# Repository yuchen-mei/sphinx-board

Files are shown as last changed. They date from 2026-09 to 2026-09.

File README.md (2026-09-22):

# Sphinx ASIC Test Board

Sphinx is a test board for voltage, frequency, power, and energy-efficiency characterization of a TSMC N7 ASIC. The nominal operating point is 0.75 V core supply, approximately 5 W during kernel execution, and a target clock frequency of 1 GHz. A local programmable regulator, distributed decoupling, and differential feedback at the socket provide the board-level power delivery path.

Hardware: **V2**. This package contains the current schematic project, local KiCad libraries, BOM, schematic exports, and design documentation. The [Pico controller source](../controller/README.md) is maintained alongside this package. There is no V2 PCB, completed host test application, or board measurement evidence in the current repository.

## Design files

Open [schematic/sphinx_power_v2.kicad_pro](schematic/sphinx_power_v2.kicad_pro) in KiCad 10.

| File | Contents |
|---|---|
| [Schematic PDF](schematic/exports/sphinx_power_v2.pdf) | Eleven schematic sheets |
| [XML netlist](schematic/exports/sphinx_power_v2.net.xml) | Component connections |
| [Parts catalog](schematic/bom/parts_catalog.json) | Exact parts, assembly options, and application notes |
| [Purchase list](schematic/bom/BUY_LIST.csv) | Quantities for five boards and spares |
| [Component list](schematic/bom/component_list.csv) | Schematic components and fields |
| [Documentation](docs/README.md) | Requirements, interfaces, layout constraints, and verification |
| [Maintenance](CONTRIBUTING.md) | Editing and validation procedure |

## Operating scope

The core regulator covers 0.30–1.20 V. The lower end supports low-voltage energy-efficiency measurements. The conservative continuous-current design target is 10 A. I/O operates at a fixed 1.8 V. The supported operating region is determined experimentally for each device and workload; the regulator range does not define an ASIC voltage rating.

The board uses explicit `SET` / `ON` commands to program and enable the supplies. Once a command completes, the regulator and board-powered GPIO expander retain the voltage, enable and explicit reset state while 12 V remains valid. Pico restart, USB disconnect, firmware stop or Pico removal does not change that state. The [autonomous power contract](docs/AUTONOMOUS_POWER.md) defines the hardware, recovery rules and acceptance tests. Independent protection and the STOP button remain active without Pico. DUT reset is a separate, active-high control: the local button, remote optocoupler, or an explicit Pico command asserts it. With valid VIO and no request, reset is released without depending on the Pico, power-good signals, or run-latch state.

Functionality testing runs one kernel and checks its output. Power testing runs a large back-to-back kernel loop and reads averaged voltage, current, and power after operation settles. Ordinary PG/undervoltage observations, PMBus warnings, and USB inactivity are reported without resetting or shutting down the DUT. Independent board core/I/O overvoltage and local temperature protection clear the hardware run latch. The core regulator and input eFuse also retain their own protection; a regulator-only fault can stop Core without clearing I/O. STOP and latched protective trips require a new explicit `ON`; internally latched eFuse faults can require cycling the 12 V input. Full board-power loss returns to OFF. Partial input brownouts are outside the state-retention guarantee and must be characterized; regulator and control-domain resets need not occur together.

The 10 A target still requires PCB resistance, loop stability, transient, socket/package, and sustained thermal qualification. Controller commissioning and calibration are required before unrestricted operation; a passing source-level check does not establish board readiness.

The controller follows the [startup interface](docs/RESET_AND_CONTROL.md). File checksums and verification scope are recorded in [PROVENANCE.json](PROVENANCE.json).

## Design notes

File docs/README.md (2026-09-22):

# Design Documentation

These documents describe the V2 schematic design and its required behavior. Start with the circuit description and operating procedure if you know the ASIC but are new to the board. Completed design checks and pending board measurements are distinguished in the verification document.

| Document | Scope |
|---|---|
| [Requirements](REQUIREMENTS.md) | Experiment, operating range, and design objectives |
| [Circuit description](DESIGN.md) | Power paths, protection, and telemetry |
| [Autonomous power](AUTONOMOUS_POWER.md) | Retained power/reset state, independent protection, command completion, and Pico-loss acceptance tests |
| [Power configuration](POWER_CONFIGURATION.md) | PMBus address, capacitor populations, and compensation settings |
| [Reset and control](RESET_AND_CONTROL.md) | Controller ON/OFF, fault latch, STOP, and local/remote reset |
| [I/O enable interface](IO_ENABLE.md) | Circuit connections and transient verification |
| [Layout requirements](LAYOUT_HANDOFF.md) | Power delivery, probing, signals, and mechanical integration |
| [Verification](VALIDATION.md) | Schematic evidence and board measurement plan |
| [Final source review](FINAL_REVIEW_2026-09-22.md) | Completed independent review, corrections, and remaining physical qualification |
| [References](REFERENCES.md) | Manufacturer documents and their applicability |

The [schematic](../schematic/exports/sphinx_power_v2.pdf), [netlist](../schematic/exports/sphinx_power_v2.net.xml), [parts catalog](../schematic/bom/parts_catalog.json), and [component list](../schematic/bom/component_list.csv) define component population and connections. Sheet 09 covers autonomous control and sheet 10 independent protection. Use [current generated evidence](VALIDATION.md) for design counts and check results; this documentation does not maintain duplicate fixed totals.

The normal workflow is one checked `ON`, an explicit reset with the external clock running, then either one kernel for functional correctness or a large back-to-back kernel loop followed by steady voltage/current/power measurements. Once a power command succeeds, continuously valid 12 V and healthy hardware retain operation through Pico inactivity, USB disconnection, reboot, or loss of Pico power. Complete board input loss defaults OFF when power returns. Measurements are requested when needed; they are not a power-sustain heartbeat.

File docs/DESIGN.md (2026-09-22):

# Circuit Description

## Power paths

The core path is J101/J102, F101, U101, U201/L201, R201, and the socket supply plane. U201 is a TPS546B24ARVFR synchronous buck regulator. L201 is 0.56 µH and the configured switching frequency is 650 kHz. Differential feedback returns from the socket-side net ties NT601 and NT602, after the 1 mΩ core current shunt R201.

At 10 A, R201 has a nominal 10 mV drop and dissipates 0.10 W. Feedback includes this shunt and the PCB path to the sense endpoint. It excludes socket and package impedance. The WSL shunts are two-terminal devices; route independent sense traces from their pads.

U301 is the fixed-output TPS62131RGTR, supplying 1.8 V through L301 and the 10 mΩ I/O shunt R301. TPS62133 is a different output-voltage variant and is not a substitute. The enable circuit is specified in [IO_ENABLE.md](IO_ENABLE.md).

U102 supplies AUX5V through the 73.2 kΩ / 10 kΩ feedback network. U901, TLV75533PDBVR, independently generates `3V3_CTRL` from AUX5V with its enable tied to AUX5V. D401 supplies Pico VSYS from AUX5V, but Pico pin 36 does not supply `3V3_CTRL`. Removing or rebooting the Pico therefore does not remove board control power. Follow the schematic power connections when combining USB and board input power.

Sheet 09 contains the autonomous control interface: U902 ISO1640BDR separates board-side I2C on side 1 from Pico-side I2C on side 2. Pico GP0/GP1 are its only GPIO connections, carrying SDA/SCL. Each bus side has its own supply and pullups. U903 TCA9535PWR retains output requests and reads digital status; U904 ADS1115IDGSR reads the NTC and its excitation supply. Sheet 10 contains independent temperature and I/O overvoltage protection. See [AUTONOMOUS_POWER.md](AUTONOMOUS_POWER.md) for the complete pin map and power-domain contract.

## Input protection and run latch

F101 is a 3.15 A backup fuse. U101 is a TPS259470L eFuse. Its 1.24 kΩ ILM resistor sets a nominal 2.69 A current limit. Input UVLO and OVLO are approximately 10.64 V and 14.4 V. These are nominal circuit thresholds; evaluate tolerances and fault transients during verification.

U509 senses VIN12 after the eFuse and reports `VIN12_VALID` to U903 P11, with R516 providing its 10 kΩ pull-up. This observation does not clear the run latch. U503 is the hardware fault latch: pin 5 is Q (`RUN_LATCH`), and its unused Q-bar output is left unconnected. STOP, an asserted eFuse fault output, control-supply brownout, independent Core/I/O overvoltage, and independent board overtemperature participate in the hardware clear path. U507 conditions the fault bus into `HW_CLEAR_N`, which asynchronously clears U503.

The controller commands U903 P03 to pulse `RUN_SET` through U507 during an explicit ON startup. R507 holds this input low before U903 is initialized. A hardware clear acts even if the Pico is absent or retained enable requests remain high; recovery alone cannot set the cleared latch again. `ON` verifies discharge and configuration, checks the fault bus, and generates one set pulse. A scale-changing SET while ON disables rail requests, checks discharge, and reconfigures while preserving the existing run latch; it restores requests only if that latch remains set and never generates another set pulse. Repeated ON at the matching established state checks it without cycling power. OFF pulses U903 P04 `CLEAR_REQUEST` high through Q901 to clear the latch, then returns P04 low. These actions preserve U903 P02's explicit DUT reset request.

The eFuse has its own operating and fault behavior. UVLO and OVLO inhibit its output without necessarily asserting its fault output. Recovery with the original operating point requires both retained control state and retained regulator configuration; a dip that resets PMBus settings while AUX/control power survives is a separate qualification case. USB does not sustain the independent control domain. Control brownout or an asserted eFuse fault clears the latch; a complete input loss and discharge defaults OFF on return. An internally latched eFuse fault can also require cycling 12 V. See [RESET_AND_CONTROL.md](RESET_AND_CONTROL.md).

U502 supervises `3V3_CTRL`. R1001 = 100 kΩ connects its CT pin to `3V3_CTRL`, selecting a nominal 300 ms startup holdoff, specified 180–420 ms. The TMP302 datasheet describes 35 ms as typical in §8.2.3 and states in §9 that U1001 becomes fully functional within 35 ms after its supply reaches 1.4 V. The 180 ms minimum holdoff provides startup margin for a normal monotonic supply ramp. Qualify the assembled clear path during hot startup and nonmonotonic supply ramps; see [AUTONOMOUS_POWER.md](AUTONOMOUS_POWER.md).

U504, a Diodes Incorporated 74LVC08AT14-13 in TSSOP-14, implements the two supply-enable AND functions:

```text
CORE_EN      = RUN_LATCH AND CORE_REQ
IO_EN_CTRL   = RUN_LATCH AND IO_REQ
```

The unused third and fourth gates have their inputs grounded and outputs unconnected. U506 and C507 are absent; no logic gate combines power-good or run-latch signals with DUT reset. U507 remains part of the power-latch circuit.

| Detector | Sense network | Nominal threshold | Function |
|---|---|---:|---|
| U501 | 1.24 kΩ / 20 kΩ | 1.319 V | Independent core overvoltage, clears run latch |
| U509 | 73.2 kΩ / 10 kΩ | 10.333 V | Post-eFuse input-voltage observation on `VIN12_VALID`; warning only |
| U508 | 6.19 kΩ / 20 kΩ | 1.626 V | I/O voltage observation on `IO_VALID`; warning only |
| U1001 | TMP302B straps: TRIPSET0 high, TRIPSET1 low, HYSTSET low | 75°C, nominal 5°C hysteresis | Independent local board-temperature protection; clears run latch |
| U1002 | R1002 = 12.6 kΩ / R1003 = 20 kΩ, both 0.1% | 2.02446 V | Independent socket-side I/O overvoltage; clears run latch |

The fixed Core OVP is a board fault threshold. The controller programs regulator overvoltage, overtemperature, and excessive-current protection once and verifies readback; protection then operates without Pico service. C1001/C1002 locally bypass U1001/U1002. TMP302B accuracy is ±2°C before placement error. The I/O comparator threshold has an approximate 1.943–2.106 V initial static screening range, not a guaranteed 2.025 V ceiling. Ordinary PG loss, undervoltage, voltage deviation, PMBus warnings, and communication loss are diagnostic observations; they do not request shutdown or reset. The 10 A continuous target and routine current budgets are qualification limits and warnings, not instantaneous current clamps. No protection threshold establishes an ASIC absolute-maximum rating.

Take the U501 sense connection independently from the socket core plane. A break in the narrow feedback branch must not also disconnect the OVP sense path. U508 directly measures I/O voltage; U301 PG alone does not establish that an operating I/O supply is present.

## Reset

R602 pulls J1.54 to I/O voltage through 10 kΩ. R603 biases Q601's base from VIO through 21.5 kΩ; R604 provides the 100 kΩ base pull-down. With valid VIO, Q601 normally conducts and pulls J1.54 low to release reset. SW601, optocoupler U601, and U903-controlled Q602 independently pull `RESET_BASE` low to turn Q601 off and assert active-high reset:

```text
RESET_ASSERTED = LOCAL_RESET OR REMOTE_RESET OR RETAINED_RESET_ASSERT
```

This expression applies while VIO provides valid logic levels. U903 P02 is `RESET_ASSERT`: high requests reset, and low releases that request. R411 keeps the request inactive when U903 is in its cold-start input state. Once programmed, this request survives Pico loss or reboot. An explicit reset command leaves the power requests and latch unchanged; power commands and protective shutdown leave the retained reset request unchanged. Reset is not automatically driven by invalid power. Its high level is unavailable when VIO is absent. There is no pulse stretcher or clock synchronizer; the operator supplies an adequate explicit pulse with the external clock running.

TP7 measures the actual J1.54 reset node; TP607 supplies the adjacent probe ground. See [RESET_AND_CONTROL.md](RESET_AND_CONTROL.md).

## Decoupling and telemetry

The default core population is 12 × 330 µF polymer, 12 × 100 µF MLCC, 16 × 1 µF, and 16 × 100 nF. Total nominal capacitance is 5177.6 µF. The board reserves four additional polymer and four additional large-MLCC positions. Assembly options and controller settings are specified in [POWER_CONFIGURATION.md](POWER_CONFIGURATION.md).

R212 (47 Ω) and R304 (100 Ω) discharge Core and I/O. Confirm output voltage before a range change or hardware reconfiguration; disabling a regulator does not immediately discharge its output.

Two INA226 devices at 7-bit addresses 0x40 (Core) and 0x41 (I/O) measure rail voltage and current. With configuration `0x4297`, four averages of 332 µs bus and 332 µs shunt conversions give a nominal 2.656 ms update period. U201 PMBus is at 0x10, U903 at 0x20, and U904 at 0x48. U904 AIN0/AIN1 measure `BOARD_NTC`/`3V3_CTRL` for a calibrated ratiometric temperature reading. Reading telemetry is optional for power retention. Use an oscilloscope for kernel transients and reset pulses.

The core shunt measures regulator current before local decoupling. Capacitor-supplied load current is not measured directly at that shunt. During a sustained back-to-back kernel loop, average capacitor charging current approaches zero, so averaged shunt current is useful for steady rail-power measurement. INA226 VBUS is referenced to its local ground; it is not a die-side differential voltage measurement. The reported rail power includes downstream board loads and socket/package losses. R212 consumes about 12 mW at 0.75 V and R304 consumes 32.4 mW at 1.8 V; account for these loads when estimating DUT supply power. Input current requires an external instrument.

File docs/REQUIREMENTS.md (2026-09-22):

# Design Requirements

## Experiment

The board supports characterization of a TSMC N7 ASIC across core voltage, clock frequency, and workload. Functionality testing runs a kernel once and compares its output with the expected result. Power testing runs the kernel in a large back-to-back loop, waits for steady operation, and reads averaged voltage, current, and power. Power delivery must accommodate both the sustained load and the transitions at kernel start and completion.

| Parameter | Requirement or experiment input |
|---|---|
| Nominal core voltage | 0.75 V |
| Active core power | Approximately 5 W at the nominal operating point, supplied as an experiment input |
| Nominal active current | Approximately 6.67 A, calculated as 5 W / 0.75 V |
| Clock frequency | 1 GHz target; higher frequencies are characterization points |
| Core adjustment range | 0.30–1.20 V; default sweep increment 50 mV |
| Continuous core current | 10 A conservative board design target |
| I/O supply | Fixed 1.8 V; 1 A provisioned load budget |
| Input supply | 12 V nominal; 11.5–13 V operating target at the input terminals |
| Control | Pico USB commands through isolated I2C, retained board-side requests, hardware fault latch and STOP, local and remote DUT reset |
| Telemetry | Core and I/O voltage/current, plus board temperature |
| Initial build | Five boards plus component spares |

The adjustment range is a superset of the intended experimental operating points. The 0.30 V lower limit supports low-voltage energy-efficiency measurements. Approximately 1.0 V is an empirically supported boost point for the available devices. No device absolute-maximum voltage is specified. Select boost voltage, frequency, and workload per device and record the measured operating conditions.

I/O voltage is fixed because the experiment does not require an I/O voltage sweep and the I/O load is small. The 1 A budget is provisioning, not a measured I/O consumption value.

Minimize routine experiment steps: one `ON` command performs configuration checks and starts the supplies. After successful completion, with continuously valid 12 V and no hardware fault or STOP, the established supply configuration and explicit reset request must survive Pico inactivity, USB disconnection, firmware restart, and complete loss of Pico power. The board must not require periodic Pico execution or bus traffic. Reset is a separate explicit user or experiment-script action. Ordinary power-good loss, undervoltage, voltage deviation, PMBus warnings, and communication loss are diagnostic; observations collected on demand must not reset the DUT or stop the experiment.

Retain independent hardware protection against damaging overvoltage, overtemperature, and excessive current, together with explicit `OFF` and hardware STOP. Board temperature and I/O overvoltage protection must not depend on software samples. A cleared run latch must not restart automatically when its cause clears; a new explicit `ON` requests recovery. Regulator/eFuse intrinsic lockout and loss of control power remain physical operating constraints. An intrinsic input interruption can recover transparently only if the control state and regulator configuration both survive; partial brownouts require qualification. After complete 12 V loss and board discharge, restored power must default OFF and require fresh configuration and explicit `ON`.

The [autonomous power contract](AUTONOMOUS_POWER.md) defines the retained interface and acceptance tests. A command interrupted before verified completion has an unknown outcome and must not be automatically replayed. Reconnecting the Pico first reads the existing board state; it must not initialize active outputs to defaults.

## Power delivery

Minimize board resistance and transient voltage excursions through local regulation, short current paths, distributed capacitance, and socket-side differential feedback. Evaluate voltage at multiple socket power/ground groups under static and pulsed loads. Record droop, overshoot, recovery time, and reset activity. Numerical droop acceptance limits are not specified.

The feedback endpoint is on the PCB. Socket contacts, bond wires, and the on-chip power grid lie beyond that endpoint. Package and socket replacement are design options. The package concerns are bond-wire geometry and encapsulant thermal conductivity; no numerical parasitic or thermal model is assigned without corresponding data.

## Reset and sequencing

DUT reset is active high at 1.8 V. The clock must run during reset. Reset release is asynchronous; no clock-synchronized release is required by the experiment. Manual reset and remote reset use pulses with ample duration rather than a minimum-cycle pulse. No numerical minimum pulse width is specified.

There is no experiment-specific requirement for the relative Core/I/O power sequence or inter-rail delay. With valid VIO and no explicit reset request, the hardware holds DUT reset released without Pico execution. The software reset request is retained by board-side U903, so a previously asserted request remains asserted through Pico loss or reboot. Neither power-good signals, the run latch, voltage deviations, nor automatic power sequencing asserts reset. Reset is asserted only by the local button, remote optocoupler input, or an explicit reset command. Its 1.8 V high level depends on VIO being present; behavior during a collapsing or absent VIO is not a guaranteed logic level.

For an intentional DUT reset, establish the supplies and run the external clock, then explicitly assert and release reset. `ON`, `OFF`, and a voltage-range change do not insert a reset pulse. A range change that requires disabling the supplies can destroy DUT state; the experiment script decides when to reset and reload the kernel afterward.

## Thermal characterization

Measure regulator, inductor, capacitor, socket, and package temperatures at the selected voltage, frequency, workload, and airflow. The board NTC provides local temperature telemetry through U904; independent U1001 protects at nominal 75°C with sensor tolerance and placement-dependent thermal error. No die junction-temperature limit is assigned in this specification.

The qualified load and airflow envelope must keep U903 junction temperature ≤100°C to satisfy its SDA sink-current limit with the selected bus pullups. U1001 measures a different location and cannot establish this condition alone. See [the control-domain limits](AUTONOMOUS_POWER.md).

Characterize continuous operation at selected operating points for eight hours, recording functional errors, resets, supply extrema, current, and temperature. Determine the usable operating region from measurements rather than extrapolating the 5 W nominal point.

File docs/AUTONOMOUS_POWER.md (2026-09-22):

# Autonomous Power Contract

This specification defines the V2 change that makes an established power state independent of the Pico. It is a design and acceptance contract; the validation matrix below is not a record of completed hardware tests. The electrical and thermal qualification requirements in [REQUIREMENTS.md](REQUIREMENTS.md) still apply.

## Required behavior

After an explicit `ON` or `SET` command completes successfully, the board must retain its requested rail enables, programmed Core operating point, and explicit reset request while the 12 V input remains continuously valid and no hardware protection or STOP is asserted. Pico inactivity, USB disconnection, firmware termination, Pico reboot, or complete loss of Pico power must not change that state. Supply regulation and protection must not depend on a heartbeat, polling loop, periodic register write, or watchdog service performed by the Pico.

The supported input target is 11.5–13 V at the board terminals. Retention means preserving the established electrical control state; it does not promise constant ASIC power consumption or eliminate load-step voltage transients. The regulators must continue regulating when the kernel starts, finishes, or runs a back-to-back loop.

The Pico is a command and measurement interface. Between explicit commands it may sleep, stop executing, or be absent. Hardware protection continues without it. A `STATUS` or measurement command can collect a fresh snapshot, but issuing those commands is optional for continued operation. Measurements collected on demand cannot reconstruct an unobserved transient or an unlogged thermal history.

A complete loss of 12 V is different from loss of Pico power: after the board supply has discharged sufficiently to reset the control domain, the next power application must start **OFF**. No retained file, default firmware setting, USB attachment, or return of 12 V may issue a start pulse automatically. Starting again requires a new explicit `ON` and successful configuration checks. This is volatile state retention while powered, not restoration from nonvolatile memory.

STOP and a fault on the shared hardware clear path override every retained enable request. Clearing their cause must not set the run latch again. A cleared latch requires an explicit `ON`; an internal latched eFuse fault may additionally require cycling the input supply. `OFF` remains an explicit command. Manual and remote DUT reset remain available independently of the Pico.

## Power and communication domains

| Device | Selected part | Board function |
|---|---|---|
| U901 | TLV75533PDBVR | Generate independent `3V3_CTRL` from `AUX5V`; EN is tied to AUX5V |
| U902 | ISO1640BDR | Carry the bidirectional I2C bus between separately powered board and Pico domains |
| U903 | TCA9535PWR | Hold rail, reset, start, and clear requests; read board status |
| U904 | ADS1115IDGSR | Measure the board NTC and its excitation supply on demand |
| U1001 | TMP302BDRLR | Independent nominal 75°C board-temperature trip |
| U1002 | TLV3011AIDBVR | Independent nominal 2.02446 V I/O overvoltage trip |

U901, the run latch and its gating logic, the hardware fault detectors, U903, U904, board-side bus pullups, and the regulator/INA interfaces belong to the board domain. Pico pin 36 must not supply or be tied to `3V3_CTRL`. U901 uses IN/EN pins 1/3 at AUX5V, GND pin 2, OUT pin 5, and NC pin 4; C901/C902 must each retain at least 1 µF effective capacitance. The selected CL21B475KOFNNNE parts are 4.7 µF, ±10%, 16 V X7R, 0805; verify bias and temperature derating in procurement/layout review. [TI TLV755P datasheet](https://www.ti.com/lit/ds/symlink/tlv755p.pdf)

Samsung marks CL21B475KOFNNNE as NRND as of 2026-09-22; this also applies to C202 on U201 VDD5. Verify procurement before ordering or separately qualify a replacement with the required effective capacitance. Dated distributor stock is not a reservation. [Samsung product page](https://product.samsungsem.com/mlcc/CL21B475KOFNNN.do)

For U902, **side 1 is the board and side 2 is the Pico**: pins 1/2/3/4 are VCC1/SDA1/SCL1/GND1, and pins 8/7/6/5 are VCC2/SDA2/SCL2/GND2. Each side has local decoupling and pullups to its own supply. The isolation barrier prevents an unpowered Pico from clamping the board bus. Shared system ground through other connections does not invalidate this power-domain separation; the assembled board must not be advertised as a galvanically isolated system. Side 1 has an 80 pF load limit and an offset low-output level, so the complete board bus requires capacitance and logic-level verification. [TI ISO1640 datasheet](https://www.ti.com/lit/ds/symlink/iso1640.pdf)

The board bus uses 2.2 kΩ pullups. Keep U903 junction temperature ≤100°C throughout the qualified operating envelope: TCA9535 Rev. F permits 3.5 mA SDA sink current at that limit but only 1 mA above it, below the current demanded by these pullups. U1001's local 75°C trip does not establish U903 junction temperature. Place U903 away from power hot spots and verify its temperature and bus levels under worst qualified load and airflow. [TI TCA9535 datasheet, §5.3](https://www.ti.com/lit/ds/symlink/tca9535.pdf)

Remove direct Pico connections to retained requests, board status, and the board-powered thermistor node. A remaining direct connection could back-power the Pico or pull down a protection input when Pico power disappears. GPIO high-impedance behavior alone is not sufficient isolation.

## Retained command and status interface

U903 has all address straps grounded and uses 7-bit I2C address `0x20`. Port assignments are:

| Port | Direction after initialization | Signal / behavior |
|---|---|---|
| P00 | Output | `CORE_REQ` |
| P01 | Output | `IO_REQ` |
| P02 | Output | `RESET_ASSERT`; high asserts the explicit software reset request |
| P03 | Output | `RUN_SET`; pulse only during an explicitly authorized start |
| P04 | Output | `CLEAR_REQUEST`; high turns on Q901 to pull `HW_FAULT_N` low |
| P05 | Input | `RUN_LATCH` |
| P06 | Input | `HW_FAULT_N` |
| P07 | Input | `CORE_PG`, diagnostic |
| P10 | Input | `IO_VALID`, diagnostic |
| P11 | Input | `VIN12_VALID`, diagnostic |
| P12–P17 | Input | Unused inputs pulled to ground individually through R1004–R1009 = 10 kΩ; keep configured as inputs |

U903 outputs persist without I2C traffic while its supply remains valid. Hardware pull-downs establish inactive rail requests, inactive start/clear requests, and released software reset at a cold start, when its ports are inputs. On a confirmed cold initialization, write safe output values before changing port directions: output register `0x02 = 0x00`, then configuration registers `0x06 = 0xE0` and `0x07 = 0xFF`; retain zero polarity inversion. The power-on output-register value is `0xFF`, so reversing this order could briefly assert every request. [TI TCA9535 datasheet](https://www.ti.com/lit/ds/symlink/tca9535.pdf)

A Pico boot or reconnection is **not** a cold initialization of U903. Attachment must first read the existing direction, output, input, and regulator state, without rewriting them. Do not create GPIO objects or drivers whose constructors reset board outputs. Unknown or inconsistent state must be reported as such; do not silently replace it with software defaults. Commands must modify only their owned output bits, preserving the explicit reset request and other retained bits.

`CLEAR_REQUEST` acts through Q901 as a pull-down; U903 must never drive the shared fault bus high. The common hardware fault line has asynchronous priority over U503. Both P03 and P04 must be low after a completed ON, OFF, or SET. OFF pulses P04 to clear the latch and then releases it. An interrupted command can leave P04 high, so a low fault-bus reading alone does not identify which external protection fired.

## Commands and completion

The transport accepts a request; a successful response is issued only after that request's required writes and readbacks complete. These are distinct events. Do not report success just because bytes were received or an I2C transaction was acknowledged.

For `ON` from OFF, the implementation must:

1. Preserve the explicit reset request. Hold rail requests and `RUN_SET` low, pulse `CLEAR_REQUEST`, verify the run latch is clear, and release the clear request.
2. Check commissioning, verify both outputs have discharged below 50 mV, program the selected Core voltage, feedback scale, compensation, and protection settings, and read them back.
3. With `CLEAR_REQUEST` released, verify the hardware fault line remains released for the startup qualification interval and generate a single `RUN_SET` pulse. Verify the latch and hardware fault line before enabling the requested rails in the configured sequence.
4. Verify the final requested outputs and regulator configuration, return `RUN_SET` low, and return the completed state. There must be no outstanding background action required to sustain it.

The nominal 0.75 V point uses feedback scale 0.5 as specified in [POWER_CONFIGURATION.md](POWER_CONFIGURATION.md). An `ON` directed at an already established matching state reads and checks that state without cycling the supplies or generating another pulse. A changed operating point must be an explicit `SET`.

A same-scale SET while ON changes the operating point without a rail power cycle. A scale-changing SET while ON turns off the rail requests, checks discharge, and reconfigures while preserving the existing run latch. It restores the prior requests only if that latch survives, and does not pulse RUN_SET. A SET while already OFF programs and verifies the target while remaining OFF. None of these paths changes the explicit reset request. SET must not recover a cleared latch or protective trip; recovery requires ON.

If Pico execution or communication is lost **during** `ON`, `OFF`, `SET`, or `RESET`, completion is unknown. A register write may already have taken effect; a multistep command is not atomic. The board may retain an intermediate rail request, clear request, reset request, or start level. No promise is made that it rolls back or completes on its own. On reconnection, read back actual state and require a deliberate recovery command; do not replay the interrupted command automatically. A start level left high must not generate repeated edges or an automatic restart when a fault clears.

If the command completed but its final USB response was lost, the same uncertainty applies to the host's knowledge, even though the board can be in its correctly retained final state. A read-only status query resolves the present state without disturbing it.

## Independent protection

| Mechanism | Required autonomous behavior | Interpretation |
|---|---|---|
| Hardware STOP | Clear U503 and inhibit both rails | Recovery requires new `ON` |
| Input eFuse | Retain its current, voltage, and thermal protections and fault connection | Intrinsic UVLO/OVLO and latched FLT events are different behaviors |
| U502 control supervisor | Clear the latch on control-power brownout and hold it clear during startup | Protects the retained control state |
| Existing Core absolute OVP | Retain the independent approximately 1.319 V hardware guard | Fixture guard with tolerance, not an ASIC maximum rating |
| TPS546B24A internal protection | Retain programmed relative OVP, excessive-current, and overtemperature protection | Operates without continued PMBus traffic; use verified response settings |
| TPS62131 internal protection | Retain its intrinsic current and thermal protection | Does not replace external I/O OVP |
| U1001 temperature switch | Pull the hardware fault bus low at nominal 75°C | Measures local board temperature, not die junction temperature |
| U1002 I/O OVP comparator | Pull the hardware fault bus low at nominal 2.02446 V | Independent of ADC readings and Pico execution |

U1001 uses pin 1 `TRIPSET0` high, pin 6 `TRIPSET1` low, pin 4 `HYSTSET` low, pin 5 at `3V3_CTRL`, pin 2 at ground, and open-drain pin 3 on `HW_FAULT_N`; C1001 is its local bypass capacitor. This selects a nominal 75°C trip with ±2°C sensor accuracy and nominal 5°C hysteresis. Cooling to approximately 70°C releases the detector; it must not restart power. Physical placement and the temperature gradient to the socket, regulator, and DUT remain qualification items. [TI TMP302 datasheet](https://www.ti.com/lit/gpn/TMP302)

U1002 uses `3V3_CTRL` on pin 6, ground on pin 2, REF pin 5 tied to IN+ pin 3, and the divided socket-side I/O rail on IN− pin 4; C1002 is its local bypass capacitor. OUT pin 1 joins `HW_FAULT_N`. Upper R1002/lower R1003 are 12.6 kΩ/20.0 kΩ, both 0.1%, giving `1.242 × (1 + 12.6/20) = 2.02446 V` nominal. The TLV3011A reference and 25°C offset limits yield an approximate initial screening range of 1.943–2.106 V before further temperature and dynamic effects. This is not a guaranteed 2.025 V ceiling. There is no feedback resistor from the shared fault bus to the divider. Use the specified A-version; changing comparator variants requires reviewing threshold and hysteresis. [TI TLV3011 datasheet](https://www.ti.com/lit/ds/symlink/tlv3011.pdf)

The historical software temperature threshold of 75°C and software I/O threshold of 2.025 V are replaced as protection mechanisms by these independent detectors. Software can report measurements and warnings, but samples must not be required to sustain or protect the rails. Likewise, an old sampled Core guard above 14 A for 100 ms or an absolute software Core guard at 1.26 V does not become an autonomous hardware guarantee merely because its constant remains in a profile. The regulator's commissioned 15 A OC setting, relative OVP at 112.5% of target, and independent fixture guards are separate mechanisms with their own accuracy, delay, and response. If the experiment requires a specific 14 A/100 ms envelope, it needs separately qualified hardware support.

The routine 8 A Core budget, 10 A continuous design target, 1 A I/O budget, ordinary PG loss, undervoltage, measurement deviation, PMBus warnings, and communication errors remain diagnostic. They must not cause software power cycling, a clear pulse, a reset request, or periodic intervention. Hardware and software thresholds are fixture commissioning choices; none establishes an ASIC absolute-maximum rating or a demonstrated 10 A board rating.

## Startup temperature and input disturbances

TMP302 §8.2.3 describes a typical 35 ms output-valid delay; §9 states functional readiness within 35 ms after VS reaches 1.4 V. U502's former CT-open delay could release in 12 ms. **R1001 = 100 kΩ connects U502 CT pin 4 to `3V3_CTRL`** to select a nominal 300 ms delay, specified 180–420 ms. Both VDD and SENSE monitor the independent control supply. The minimum supervisor delay exceeds the stated detector readiness interval by 145 ms for normal monotonic startup. Qualify the complete clear path during hot startup, including nonmonotonic supply ramps and temperature corners. An above-threshold board must remain inhibited even with a pending ON attempt; cooling alone must not set the latch. [TI TPS3808 datasheet](https://www.ti.com/lit/ds/symlink/tps3808.pdf), [TI TMP302 datasheet](https://www.ti.com/lit/gpn/TMP302)

Input undervoltage indication is not a DUT reset request. An input disturbance can nevertheless interrupt energy delivery through the regulators' or eFuse's intrinsic limits. The following cases must be distinguished:

| Disturbance | Required interpretation |
|---|---|
| Pico/USB loss with valid 12 V and `3V3_CTRL` | Retain board state and output configuration; no rail or reset disturbance caused by the controller loss |
| Input dip while the control domain and regulator configuration remain valid | Physical regulation may be lost; intrinsic UVLO/OVLO recovery can restore output if no latched protective clear occurred |
| `3V3_CTRL` falls through the supervisor threshold | Clear the run latch; recovery of control voltage alone cannot start the rails |
| Regulator loses configuration while control/latch state survives | Original operating-point retention is not guaranteed; this partial-power case must be characterized and must not be claimed as transparent recovery |
| Complete input loss and discharge | All volatile board control state is reset; restored input defaults OFF and requires fresh configuration plus explicit `ON` |

The valid-input retention contract does not cover arbitrary input brownouts. Qualification must determine the duration/depth boundaries of partial-power cases, including whether Core PMBus settings can reset while AUX/control power remains alive. Where such a case cannot retain a safe known configuration, the implementation needs an appropriate hardware inhibit or an explicitly constrained operating envelope. The `VIN12_VALID` diagnostic alone is not that inhibit.

## Temperature and power measurements

U904 uses 7-bit address `0x48`. AIN0 reads `BOARD_NTC`, formed by R408 = 100 kΩ to `3V3_CTRL` and R409 = 100 kΩ NTC, B = 4250 K, to ground. AIN1 reads `3V3_CTRL` directly; AIN2 and AIN3 are grounded. Use a conversion range that covers 3.3 V, such as ±4.096 V, and a consistent range for the ratio. Compute `r = V(AIN0)/V(AIN1)` and, before calibration corrections, `R_NTC = 100 kΩ × r/(1-r)`. Reject invalid ratios and stale or failed conversions.

The ADS1115 input is not an ideal infinite-impedance voltmeter: at ±4.096 V its typical differential/common-mode input impedances are 15 MΩ/6 MΩ. The 100 kΩ thermistor network therefore needs loading, settling, resistor/NTC tolerance, and temperature calibration review. This channel is telemetry only; its failure or inaccuracy cannot disable U1001 protection. The thermistor's B25/50 approximation is not a substitute for its full resistance/temperature characteristic. [TI ADS1115 datasheet](https://www.ti.com/lit/ds/symlink/ads1115.pdf)

For functionality, run one kernel and compare the output. For power, execute a large back-to-back kernel loop, wait for the electrical and thermal conditions to settle, then request averaged INA226 rail voltage, current, and power. Record the operating point, clock, warning/status snapshot, and measurement conditions. No polling is needed to keep the loop powered; periodic host measurements are an optional data-acquisition choice. INA telemetry does not capture every load transient, and rail power includes downstream board losses rather than isolating die power.

## Acceptance matrix

Use a dummy load before DUT commissioning. Observe both socket rails, `3V3_CTRL`, the run latch, fault bus, and DUT reset as appropriate. A scope verifies transients and absence of unwanted edges; readback verifies configuration. Repeat relevant tests with the requested reset released and asserted, with both feedback scales, and at representative idle and high-load operating points. These are required tests, not claims that they have passed.

| Test | Stimulus | Pass condition |
|---|---|---|
| Cold default | Apply 12 V with Pico absent, blank, or booting | Both outputs remain inhibited; no start edge; explicit software reset request is inactive |
| One-command start | Complete commissioned `ON` and all readbacks | Requested rails/configuration established; `RUN_SET` low; no further software action required |
| No traffic | Stop commands and polling through the experiment interval | No control-state changes or controller-induced rail/reset interruption |
| USB disconnect | Unplug/reconnect USB after successful command | Established board state unchanged; reconnect does not rewrite it |
| Pico reboot | Reset Pico, restart firmware, or enter its bootloader | Board state and reset request retained; startup code is read-only toward active controls |
| Pico power loss | Remove only Pico power, leaving 12 V and load present; restore later | No board-bus clamp/back-power path that changes state; rails and explicit reset request retained |
| Diagnostic access | Issue `PING`, `STATUS`, and measurement commands | No start/clear edges, rail cycle, or reset-request change |
| Bus fault | Interrupt or hold the Pico-side bus during idle/reads | No software power intervention; STOP and independent protection still work |
| STOP | Assert and release STOP with Pico absent | Both rails inhibited; no automatic restart after release |
| Temperature trip | Heat U1001 through its threshold with Pico absent, then cool | Hardware clear observed; threshold/hysteresis recorded; cooling does not restart |
| Hot startup | Apply input above the thermal threshold, including a pending ON attempt | Supervisor holdoff and detector inhibit startup; no transient rail enable |
| I/O OVP | Inject a controlled I/O sense overvoltage with Pico absent | Hardware trip with measured threshold and latency; no restart after removing fault |
| Core/other protection | Exercise commissioned Core OV/OC/OT and eFuse fault cases | Their documented hardware responses occur without Pico execution; fault-bus trips remain latched OFF |
| Warning only | Exercise ordinary PG/UV/measurement warnings and communication loss | No commanded shutdown or DUT reset; intrinsic regulator operating limits still apply |
| Full input loss | Remove 12 V long enough to discharge board control/storage, then restore | No automatic start; next ON reprograms and verifies configuration |
| Partial brownout | Sweep input dip depth/duration, slow ramps, and rapid interruptions | Capture rail and control behavior; identify every retained/reset configuration case and prohibit unsupported recovery claims |
| Command interruption | Stop Pico at each write/readback/start/sequence boundary | No fabricated success; state reported unknown until readback; no automatic replay or repeated start pulses |
| Lost response | Drop USB after final board update but before host receives completion | Read-only reattachment identifies actual state without changing it |
| Explicit OFF/RESET | Complete OFF; separately assert/release RESET while ON | OFF remains OFF without Pico; RESET changes only the explicit request and does not alter rail enables |
| Kernel transitions | Run the one-shot functional kernel and sustained back-to-back loop | Record droop, overshoot, recovery, steady power, and thermal behavior; controller independence does not substitute for power-integrity qualification |

Record firmware revision, assembly, supply/temperature conditions, measured thresholds, scope captures, and readback results for each accepted operating envelope. Until these tests and the separate PCB/layout qualification are complete, this document defines intended behavior rather than verified hardware performance.

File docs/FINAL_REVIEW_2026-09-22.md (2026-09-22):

# V2 Final Source Review — 2026-09-22

The reviewed source has no remaining identified schematic, pin-mapping, or companion-controller defect that prevents the specified autonomous operation. This is a source-review result, not fabrication release or proof of 10 A continuous operation. The repository contains no V2 PCB or assembled-board measurements.

The operating contract is unchanged: run one kernel for functional correctness; use a large back-to-back loop and settled voltage/current readings for power. After a completed power command, continuously valid input and healthy hardware retain the programmed supplies and explicit reset request without Pico execution. STOP and hardware protection remain independent. Interrupted commands require readback; complete board-power loss defaults OFF.

## Completed checks

| Scope | Result |
|---|---|
| Fresh KiCad 10.0.5 ERC | 0 violations across 11 sheets, with the configured ignored checks recorded in the report |
| Fresh schematic export versus committed export | All 247 component records, 146 nets, pin attributes and library-part definitions match; only export metadata differs |
| Control connectivity | 270 contract pins pass; 236 procurement references and 75 order lines checked |
| Independent device pin review | 158 existing active-device pin expectations and 86 new control/protection pin expectations pass |
| Actual loaded footprints | All 247 symbol-pin/pad sets match; all component-list values, ordering codes and footprints match the netlist |
| ASIC and Pico | All 80 ASIC positions match the supplied bonding reference; all 40 Pico positions match the separated power/interface domains |
| Power polarity and return | All 16 polymer capacitor polarities correct; U201 DRTN connects only to C203 negative |
| Socket keepout | Four corrected local-coordinate regions load, move and rotate with the footprint; copper-layer and footprint exclusions checked |
| Schematic visual review | All 11 exported pages rendered and inspected |
| Companion firmware | 51 host tests pass on CPython 3.13.5; syntax checks pass |
| Interrupted commands | 122 accepted-write interruption points tested across ON, OFF, SET and RESET; fresh controller attachment and STATUS do not rewrite retained control state |
| USB transport | Binary input and bounded single-byte output tested, including stalled/slow hosts, malformed input and raw Unicode serialization |

The [full pin/footprint evidence](evidence/full_pinout_review.json), [new hardware pin evidence](evidence/autonomous_pinout.json), [control checks](evidence/hardware_review.json), [ERC](evidence/erc.json), [intentional net changes](evidence/autonomy_netlist_diff.json), and [keepout checks](evidence/socket_keepout.json) record the checked source. [Documentation evidence](evidence/documentation_validation.json) records exact companion firmware hashes. [PROVENANCE.json](../PROVENANCE.json) binds these reports to the current design files.

## High-current and interface screening

These calculations use the present BOM and programmed 650 kHz switching frequency. They are design screens, not measurements.

| Check | Recomputed result |
|---|---|
| Input at 1.2 V × 10 A Core, 1.8 V × 1 A I/O, assumed 80% conversion efficiency, 0.6 W AUX and 11.5 V input | Approximately 1.552 A; excludes extra external loads and inrush |
| U101 current-limit screen, R105 = 1.24 kΩ ±1% | Approximately 2.689 A nominal; 2.396 A using −10% current-limit accuracy and +1% resistor tolerance |
| Minimum output pulse at 0.30 V, 13 V input | Approximately 35.50 ns, above U201's 20 ns maximum minimum-on-time parameter |
| L201 at 1.2 V/13 V and −20% inductance | Approximately 3.740 A peak-to-peak ripple, 11.870 A peak and 10.058 A RMS at 10 A average; below the listed inductor reference ratings |
| Core 1 mΩ / I/O 10 mΩ shunts at 10 A / 1 A | 10 mV drop each; 0.10 W / 0.01 W dissipation |
| Fitted Core capacitance | 5177.6 µF nominal; 6897.6 µF with all optional bulk positions fitted; effective capacitance and stability require qualification |
| ISO1640 low-level margins | Approximately 90 mV toward TPS546B24A and 80 mV in the reverse direction, before noise and ground offsets; require measurement |

Component limits were checked against [TI TPS25947](https://www.ti.com/lit/ds/symlink/tps25947.pdf), [TI TPS546B24A](https://www.ti.com/lit/ds/symlink/tps546b24a.pdf), [Coilcraft XAL1030](https://www.coilcraft.com/getmedia/7b108457-7731-456d-9256-ca72f2e1a551/xal1030.pdf), and [TI ISO1640](https://www.ti.com/lit/ds/symlink/iso1640.pdf). No electrical rating has been inferred for the socket from mechanical dimensions. Kelvin feedback compensates PCB delivery loss up to the sense endpoint; socket contacts, bond wires and the die power grid remain downstream.

## Corrections from the final review

The CL21B475KOFNNNE lifecycle field incorrectly said Active. The parts catalog and purchase-list notes now identify the manufacturer's NRND status for C202/C901/C902 and distinguish dated stock observations from procurement availability. The electrical selection remains 4.7 µF, ±10%, 16 V X7R, 0805; qualify any replacement and its effective capacitance before substitution. [Samsung product page](https://product.samsungsem.com/mlcc/CL21B475KOFNNN.do)

The TMP302 startup description now accounts for both the typical 35 ms application response and §9's statement of readiness within 35 ms after VS reaches 1.4 V. U502's 180 ms minimum holdoff provides margin during normal monotonic startup; assembled-circuit hot-start and disturbed-supply tests remain required. [TI TMP302](https://www.ti.com/lit/gpn/TMP302)

The control-bus temperature constraint is now explicit. TCA9535 Rev. F reduces its SDA sink-current allowance to 1 mA above 100°C junction temperature, which does not support the selected 2.2 kΩ pullups. The qualified operating envelope must keep U903 at or below 100°C junction temperature and verify receiver levels; U1001's local 75°C measurement does not prove U903 temperature. [TI TCA9535, §5.3](https://www.ti.com/lit/ds/symlink/tca9535.pdf)

## Required before hardware qualification

The 10 A requirement remains a board design target. Regulator rating and correct pin connections alone do not establish copper/via capacity, loop stability, socket current distribution, contact heating, or DUT transient voltage. Complete the layout extraction, mechanical/assembly checks and load measurements in [LAYOUT_HANDOFF.md](LAYOUT_HANDOFF.md) and [VALIDATION.md](VALIDATION.md).

Qualify both feedback scales, effective output capacitance, low-voltage minimum on-time, protection thresholds and latency, input-power margins, socket-side power distribution, sustained heating and kernel start/stop transients. The ASIC absolute-maximum limits and numerical allowable droop are not supplied. No socket current rating is inferred from its mechanical drawing.

The isolated board bus still requires the ≤80 pF load check and noise-margin measurements. Pico removal/reconnection, actual MicroPython/USB execution, partial input brownouts, hot startup and the independent protection paths require physical tests. Firmware profile confirmation remains a commissioning step; it must not be bypassed merely because host tests pass.

The companion firmware remains outside this schematic repository at `../controller`, as specified by [repository maintenance](../CONTRIBUTING.md). Its files and tests were reviewed together with this design, but they are not included in this repository's commit or push. The recorded hashes identify exactly which companion revision was tested. New-part inventory has not been rechecked comprehensively.

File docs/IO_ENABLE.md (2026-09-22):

# I/O Regulator Enable Interface

U301 EN is supplied from local VIN12 through a resistive divider. Logic powered by independent `3V3_CTRL` controls MOSFET gates and does not directly drive EN. U903 retains `IO_REQ` without Pico execution; USB/Pico power loss must not change an established enable state while board input power remains valid.

## Connections

| Component | Value / type | Connection |
|---|---|---|
| R305 | 2.2 kΩ, 1%, 0.25 W, 1206 | VIN12 to IO_EN |
| R303 | 270 Ω, 1%, 0603 | IO_EN to ground |
| Q301 | DMN62D2UQ-7 | Gate IO_EN_CTRL; source ground; drain IO_EN_PULLDOWN |
| Q302 | DMN62D2UQ-7 | Gate IO_EN_INHIBIT; source ground; drain IO_EN |
| R306 | 10 kΩ | VIN12 to IO_EN_INHIBIT |
| R307 | 270 Ω | IO_EN_CTRL to ground |
| R308 | 100 Ω, 0.5 W, 0805 | IO_EN_INHIBIT to IO_EN_PULLDOWN |
| C306 | 1 nF, 50 V, C0G, ±5% | VIN12 to IO_EN_INHIBIT |
| C307 | 100 pF, 100 V, C0G, ±5% | IO_EN to ground |

Q301 and Q302 use gate/source/drain pins 1/2/3. U504 pin 6 drives `IO_EN_CTRL`, the AND of `RUN_LATCH` and U903 P01 `IO_REQ`. Hardware STOP or a fault clears the latch and overrides a retained high request.

With the command low or control power absent, R306 biases Q302 on and inhibits U301. A high command turns Q301 on, discharges the Q302 gate through R308, and permits the VIN12 divider to enable U301. The unloaded nominal divider voltage is 1.31 V at 12 V input.

C306 couples VIN12 startup edges into the inhibit gate. R308 controls gate discharge, R307 holds the logic-side gate low, and C307 controls EN-node transients. Fit all three resistors and both capacitors with the specified values. Changes require a new transient evaluation.

## Ratings and layout

The TPS6213x EN absolute-maximum range is −0.3 V to VIN + 0.3 V. Its specified enable and disable levels are 0.9 V and 0.3 V. The circuit must satisfy these limits at the U301 pins during startup, operation, and input loss. See the [TI datasheet](https://www.ti.com/lit/ds/symlink/tps62130.pdf).

At 14.4 V with EN low, R305 dissipates approximately 95 mW including its −1% resistance tolerance. Use the specified 0.25 W, 1206 part. R307 dissipates approximately 49 mW at 3.6 V and −1% resistance tolerance. Check local resistor temperatures and manufacturer derating.

Place the interface close to U301. Use local VIN12 and ground connections, short gate/drain traces, and low-inductance access to VIN, EN, and SS/TR. C307's exact part number is listed as NRND in the dated catalog; qualify any substitute for capacitance, dielectric, tolerance, and package.

## Verification

Measure VIN, EN, IO_EN_CTRL, and IO_EN_INHIBIT during cold startup, command transitions, Pico-only power loss/recovery, and rapid input interruption with USB both present and absent. Confirm Pico loss does not disturb an established enable. Input loss can remove independent control power even with USB present. Include the fastest measured supply edges and the intended temperature range. Verify `EN − VIN ≤ 0.3 V`, `EN ≥ −0.3 V`, and the enable/disable thresholds.

Also measure SS/TR during rapid VIN collapse; its pin rating depends on VIN. A static divider calculation does not establish transient pin compliance. Use measured parasitics and probe loading when interpreting the waveforms.

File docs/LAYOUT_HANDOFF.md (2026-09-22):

# PCB Layout Requirements

Use the current schematic sheets, local libraries, [netlist](../schematic/exports/sphinx_power_v2.net.xml), and BOM under `schematic/` as the electrical input. Sheet 09 adds autonomous control and sheet 10 adds independent protection. Obtain sheet/component/net counts from [generated design evidence](VALIDATION.md), not a duplicated fixed total. The current repository contains no V2 PCB.

## Power and return paths

Select stackup, copper thickness, and via construction from DC resistance, thermal, signal-integrity, and manufacturing requirements. The core continuous-current target is 10 A. Extract the hot PCB supply-and-return resistance from the load side of R201 to the socket; the layout objective is ≤1 mΩ, excluding the shunt, socket, and package.

Connect all 29 VDD and 25 VSS contacts with adequate copper and vias. Include I/O return current in the ground analysis. Inspect voltage and current density at each pin group rather than relying on one sense location.

Place NT601 and NT602 at adjacent socket-side power and ground groups. Route CORE_SENSE_P/N together without load current and away from switching nodes. Apply the TPS546B24A differential-sense routing and filtering guidance during layout review. The current schematic has no dedicated loop-injection resistor; define the measurement provision before routing is finalized.

Take shunt measurement traces independently from R201/R301 pads. Place INA226 input filters at the monitors. Reference the core monitor ground near the socket return. Take independent Core and I/O OVP sense from their socket planes; avoid a single narrow branch whose failure disconnects both regulation feedback and protection.

Keep U201 input switching loops, bootstrap connections, and local ceramic bypass compact. Connect DRTN only to C203 negative. Implement AGND, PGND, and exposed-pad connections according to the TI layout guidance. Keep ILM connected only to local R105, with parasitic capacitance below the device limit.

Route the positive and negative input paths for the same current. J101 has both pins on VIN_RAW; J102 has both pins on ground. Mark polarity clearly. Verify the AMASS 15.7 mm pin pitch, drill, pad, and body dimensions against the physical connector.

## Capacitors and measurement access

Place four groups of large core capacitors around the socket, each with three fitted polymer and three fitted large MLCC parts plus one optional position of each type. Keep all eight DNP capacitor positions electrically effective and accessible for assembly. Place 0402 decoupling near the relevant supply/return contacts. Check effective capacitance, mounting inductance, and PDN resonances.

Provide adjacent power/ground probe pads at the socket pin groups and regulator output. Provide space for a local pulsed load and loop measurement. J601 is for a high-impedance differential probe and is not a load connector. A dedicated high-current pulsed-load connector and synchronized trigger interface are not present in this schematic; resolve their physical implementation during layout review.

Place TP7 and TP607 near J1.54, on the same accessible face, with pad centers no more than 2 mm apart. Keep the reset stub and ground path short. Mark RESET and GND and preserve access with the socket closed. Both pads are 1 mm diameter.

Connect R603 to local VIO so Q601 releases reset whenever VIO is valid and no explicit request is asserted. Keep the three `RESET_BASE` pull-down paths from SW601, U601, and Q602 intact. Q602 gate is U903 P02 `RESET_ASSERT`, with R411 holding it low when U903 is uninitialized or unpowered; its initialized state persists through Pico loss. Route `CORE_PG`, `IO_VALID`, and `VIN12_VALID` to U903 diagnostic inputs without reset or run-latch clear connections. U509 retains its own R516 pull-up on `VIN12_VALID`. U501, U1001, and U1002 remain independent protective clear sources.

Implement the U301 enable interface placement requirements in [IO_ENABLE.md](IO_ENABLE.md). Keep comparator sense lines, NTC wiring, and clock routing clear of switching-node coupling.

## Independent control and protection

Power `3V3_CTRL` from U901 on AUX5V, not Pico pin 36. Place U901 input/output capacitors locally and verify effective capacitance and LDO dissipation. The Pico-side and board-side U902 supplies and bus pullups must remain distinct even though system grounds can be common. GP0/GP1 SDA/SCL are the only board-connected Pico GPIO. Do not reintroduce a direct control, status, or ADC wire that bypasses this separation.

U902 ISO1640BDR side 1 is the board, side 2 the Pico. Keep the board-side bus within its 80 pF load limit, including all device pins, traces, connectors, and probes. Check low-level compatibility with every device, aggregate pullup resistance, rise time, and the selected bus frequency. Place a bypass capacitor at each side's supply pins. Retention testing must include the Pico side unpowered and reconnecting.

Keep U903 away from power hot spots and establish its junction temperature ≤100°C at the qualified worst load and airflow. Above this temperature, the TCA9535 Rev. F SDA current allowance falls to 1 mA, insufficient for the present 2.2 kΩ pullups. Measure local temperature and bus levels; the temperature at U1001 is not a substitute.

Place U903 and its request pull-downs near control logic. Route P04 `CLEAR_REQUEST` to Q901's gate; Q901 alone pulls down the common fault bus. Keep the asynchronous clear path short and independent of the I2C bus. R1004–R1009 individually pull unused U903 P12–P17 inputs to ground through 10 kΩ. R1001 = 100 kΩ connects U502 CT to `3V3_CTRL`; keep its supervisor sense and supply connections on that independent rail.

Place U1001 TMP302BDRLR where local board temperature is intended to be protected, with C1001 close to supply/ground. Document the thermal relationship to the regulator, socket, and NTC; a 75°C sensor threshold is not a die-temperature limit. Review the TI DRL SOT-563 land pattern against the local footprint and assembly process.

Place U1002 and C1002 with short supply/ground and sense paths. R1002 = 12.6 kΩ and R1003 = 20 kΩ form the independent I/O OVP divider. Do not route its sense branch through the NTC/ADC circuitry or add positive feedback from the shared fault bus. Keep U904's AIN0 NTC and AIN1 excitation-supply routes quiet; their conversion accuracy affects telemetry, not temperature protection. See [AUTONOMOUS_POWER.md](AUTONOMOUS_POWER.md) for pin-level requirements and tolerance limits.

## Socket and package

The schematic uses J1 = 3M 280-5205-01 for a 12 × 12 mm, 0.5 mm-pitch QFN80 package. The 80 functional positions comprise 29 VDD, 25 VSS, 10 VDDPST, seven signals, and nine NC positions. The center thermal probe has no electrical connection in this design.

Use the manufacturer drawing to check the approximately 30 × 30 mm body, 17 mm height, 3.2 mm actuation stroke, pin orientation, support regions, and mounting holes. Maintain clearance for socket actuation, device insertion, probing, airflow, and rework. Resolve footprint and keepout dimensions before fabrication.

Package and socket replacement remain design options. A replacement requires a corresponding pinout, footprint, mechanical envelope, power-path, and thermal review. Do not assign package resistance, bond-wire inductance, or encapsulant thermal conductivity without applicable data.

## Clock and JTAG

Route J5 to J1.48 as a single-ended 50 Ω clock trace with a ±10% manufacturing impedance target, continuous ground reference, and short branches. J1.47 clock_tap is a separate signal. R601 = 49.9 Ω is DNP by default.

The experimental clock source is an HP8133A with a square-wave setting of 1.8 Vpp and 0.9 V offset. Record the actual output configuration and measure receiver-side amplitude, duty cycle, and ringing. The instrument load setting is not established in the setup record; do not infer a doubled receiver voltage from the front-panel amplitude alone.

J2/J6 JTAG VTref is 1.8 V. VTref is a reference input to the adapter, not a source of board power. External clock and JTAG drivers must be inactive or high impedance before VIO falls.

## Layout deliverables

Supply the stackup, impedance specification, DC resistance extraction, capacitor placement review, thermal plan, socket fit check, probe/load access plan, and PCB-to-schematic connectivity check. Report actual extracted quantities and measurement conditions. Board and package contributions must remain distinguishable.

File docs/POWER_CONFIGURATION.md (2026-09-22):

# Power Configuration

## Controller interface

The TPS546B24A uses the 7-bit PMBus address **0x10**. R209 is 4.64 kΩ from ADRSEL to ground with no upper resistor; SYNC uses automatic detection. All addresses below are 7-bit values, not shifted address bytes.

| Device | Address | Purpose |
|---|---|---|
| U201 TPS546B24A | 0x10 | Core configuration and regulator status |
| U903 TCA9535 | 0x20 | Retained control requests and digital status |
| U302 INA226 | 0x40 | Core rail measurements |
| U303 INA226 | 0x41 | I/O rail measurements |
| U904 ADS1115 | 0x48 | NTC and its excitation supply measurements |

Pico GP0/GP1 carry SDA/SCL through U902 ISO1640BDR. Side 1 and its pullups use independent `3V3_CTRL`; side 2 uses Pico power. The listed devices are on the board side and remain powered independently of the Pico while the board input is valid. U903, the run latch, and regulator registers hold the established configuration without periodic Pico work. A Pico reboot must first read these states, not reset them. Complete input loss and board discharge require fresh configuration before a new explicit `ON`.

Program and read back the regulator configuration while the output is disabled. Match compensation to the fitted capacitor population and feedback scale. Set the switching frequency to 650 kHz and soft-start time to 5 ms. The hardware MSEL straps provide startup settings and do not replace runtime configuration.

The controller uses feedback scales 1 and 0.5 to cover the 0.30–1.20 V fixture range. The TI register and operating-range descriptions differ at the 0.70–0.75 V scale-1 endpoint; use scale 0.5 for the nominal 0.75 V point and verify the selected scale and voltage before loading the ASIC. Change scale with both outputs disabled and confirm discharge below 50 mV before reconfiguration. A scale change does not assert reset automatically. The experiment operator decides whether to request reset before or after the power interruption; a meaningful reset pulse requires VIO and a running clock.

The [companion Pico firmware](../../controller/README.md) performs configuration readback, discharge checks, and explicit control through the [ON/OFF and fault-latch interface](RESET_AND_CONTROL.md). Confirm its commissioning profile before enabling the DUT. ON startup verifies configuration and pulses U903 P03 `RUN_SET` before enabling outputs. A scale-changing SET while ON disables rail requests, checks discharge, and reconfigures without clearing or pulsing the run latch; only a surviving latch permits restoration of the previous running requests. A SET while OFF programs and verifies the target without starting the rails. Power commands preserve U903 P02's reset request. Once a command completes, power and protection operate without continued firmware execution. Interrupted commands have unknown outcomes; read back state before recovery, as specified in [AUTONOMOUS_POWER.md](AUTONOMOUS_POWER.md).

## Capacitor population

| Population | 330 µF polymer | 100 µF MLCC | 1 µF | 100 nF | Nominal total |
|---|---:|---:|---:|---:|---:|
| Default | 12 | 12 | 16 | 16 | 5177.6 µF |
| Full | 16 | 16 | 16 | 16 | 6897.6 µF |

Default DNP positions are C704, C708, C764, C768, C714, C718, C774, and C778. R601, the clock termination resistor, is also DNP. Preserve all capacitor footprints and their short power/ground connections in layout.

Distribute the large capacitors in four socket-local groups. Each group fits three polymer and three large MLCC parts by default, with one additional position of each type. Place the 0402 parts at the corresponding power and return pins. Polymer capacitor polarity is positive stripe to Core.

Nominal capacitance is an assembly quantity. Use effective capacitance, ESR, and mounting parasitics for layout analysis and board verification.

## Compensation configuration

The configuration values below are controller programming inputs. Loop stability and transient response require measurements on the assembled board.

Common current-loop settings: GMI = 100 µS, RVI = 20 kΩ, CZI = 799.2 pF, CPI = 12.8 pF.

| Population | SCALE_LOOP | GMV | RVV | CZV | CPV | B1 value |
|---|---:|---:|---:|---:|---:|---|
| 12 + 12 | 1 | 25 µS | 120 kΩ | 750 pF | 6.25 pF | `0xC913826102` |
| 12 + 12 | 0.5 | 50 µS | 120 kΩ | 750 pF | 6.25 pF | `0xC913C26012` |
| 16 + 16 | 1 | 50 µS | 80 kΩ | 1000 pF | 6.25 pF | `0xC913024112` |
| 16 + 16 | 0.5 | 100 µS | 80 kΩ | 1000 pF | 6.25 pF | `0xC913824022` |

B1 is a five-byte SMBus block, least-significant byte first. For the default population at scale 0.5, the block count and payload are `05 12 60 C2 13 C9`. A readback mismatch must inhibit output enable.

Configure current limits and voltage protection explicitly. Write and read back `PGOOD_CONFIG` (E3h) = `0x009F`, retaining the documented manufacturer default, and `MISC_OPTIONS` (EDh) = `0x0000`, retaining PGD as a power-good output. The TI PGOOD register figure and field table differ in their read/write annotations; this design does not depend on changing the disputed PG mask bits. PG remains diagnostic and never controls DUT reset. Read the detailed PMBus status registers separately from PG. Disable automatic undervoltage fault shutdown used solely as an experiment pass/fail criterion while retaining damaging overvoltage, excessive-current, and overtemperature protection. Record warning and fault status so failed characterization points remain distinguishable from protective trips.

Measurements requested by the host can warn above the routine 8 A Core budget, the 10 A continuous board target, and the 1 A I/O budget. No sampled software limit is required for protection or power retention. Configure and read back the regulator's commissioned 15 A overcurrent fault, relative OVP at 112.5% of target, and overtemperature response. Retain the independent approximately 1.319 V Core hardware OVP, U1001 nominal 75°C temperature switch, and U1002 nominal 2.02446 V I/O OVP. Their tolerance and response requirements are detailed in [AUTONOMOUS_POWER.md](AUTONOMOUS_POWER.md); none is an exact ASIC damage limit. The former sampled 14 A/100 ms software guard is not a hardware timing guarantee. Review all settings for the actual DUT and qualify protection responses and loop stability on the assembled fixture. These settings do not certify 10 A continuous board operation.

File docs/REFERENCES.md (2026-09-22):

# References

Exact component datasheet links are also recorded in the [parts catalog](../schematic/bom/parts_catalog.json).

| Document | Application |
|---|---|
| [TI TPS546B24A](https://www.ti.com/lit/ds/symlink/tps546b24a.pdf) | Core regulator, ADRSEL, compensation, protection, and layout |
| [TI TPS6213x](https://www.ti.com/lit/ds/symlink/tps62130.pdf) | Fixed 1.8 V regulator and VIN-relative EN/SS/TR ratings |
| [TI TPS25947](https://www.ti.com/lit/ds/symlink/tps25947.pdf) | Input eFuse, thresholds, fault behavior, and ILM routing |
| [TI TLV3011](https://www.ti.com/lit/ds/symlink/tlv3011.pdf) | Comparator and reference specifications |
| [TI TLV755P](https://www.ti.com/lit/ds/symlink/tlv755p.pdf) | U901 independent 3.3 V LDO, enable, and effective-capacitance requirements |
| [TI ISO1640](https://www.ti.com/lit/ds/symlink/iso1640.pdf) | U902 board-side/Pico-side I2C separation, power-down behavior, logic levels, and bus loading |
| [Yageo RT-series V17](https://yageogroup.com/content/datasheet/asset/file/PYU-RT_1-TO-0-01_ROHS_L) | R1002 exact12.6k ordering code,0.1% tolerance,25ppm/C and0603 ratings |
| [TI TCA9535 Rev. F](https://www.ti.com/lit/ds/symlink/tca9535.pdf) | U903 retained outputs, power-on defaults, direction registers, address straps, and junction-temperature-dependent SDA current |
| [Samsung CL21B475KOFNNNE](https://product.samsungsem.com/mlcc/CL21B475KOFNNN.do) | C202/C901/C902 specifications and NRND manufacturer status checked 2026-09-22 |
| [TI ADS1115](https://www.ti.com/lit/ds/symlink/ads1115.pdf) | U904 temperature telemetry, conversion range, and analog input loading |
| [TI TMP302](https://www.ti.com/lit/gpn/TMP302) | U1001 B-version 75°C straps, hysteresis, accuracy, startup time, and DRL footprint |
| [TI TPS3808](https://www.ti.com/lit/ds/symlink/tps3808.pdf) | U502 control supervisor and R1001-selected 300 ms nominal startup holdoff |
| [TI SN74LVC1G74](https://www.ti.com/lit/ds/symlink/sn74lvc1g74.pdf) | DCU latch pinout and asynchronous clear |
| [Diodes 74LVC08A](https://www.diodes.com/datasheet/download/74LVC08A.pdf) | U504 quad AND, TSSOP-14 pinout, output drive, and power-off leakage |
| [TI INA226](https://www.ti.com/lit/ds/symlink/ina226.pdf) | Rail telemetry and conversion timing |
| [Diodes DMN62D2UQ](https://www.diodes.com/assets/Datasheets/DMN62D2UQ.pdf) | I/O enable, retained explicit-reset, and hardware-clear pull-down MOSFETs |
| [Toshiba TLP293](https://toshiba.semicon-storage.com/info/docget.jsp?did=14419&prodName=TLP293) | Remote-reset optocoupler and GB selection |
| [3M 280-5205-01 drawing](https://datasheet.octopart.com/280-5205-01-3M-datasheet-21189636.pdf) | QFN80 socket dimensions and footprint |
| [TSMC 2020 Annual Report, p. 14](https://investor.tsmc.com/static/annualReports/2020/english/ebook/files/basic-html/page14.html) | N7 automotive foundation-IP qualification context |

The 3M drawing does not specify a contact-current rating. No numerical socket current rating is assigned here.

The TSMC report describes qualification of N7 automotive foundation IP. It does not specify the junction-temperature limit of this ASIC. This project therefore assigns no junction-temperature rating from that process-level statement.

Experiment inputs are defined in [REQUIREMENTS.md](REQUIREMENTS.md): 0.75 V nominal Core, fixed 1.8 V I/O, approximately 5 W active core power, empirical boost operation around 1.0 V, explicit active-high reset with a running clock, asynchronous reset release, and no specified inter-rail sequence constraint. Functionality runs one kernel; power uses a large back-to-back loop followed by steady averaged readings. Ordinary PG/undervoltage observations are diagnostic and do not automatically reset or stop the experiment. These inputs do not constitute manufacturer absolute-maximum ratings.

The [autonomous power contract](AUTONOMOUS_POWER.md) specifies how these parts are used together. Datasheet state retention and fault behavior do not prove assembled-board behavior during partial supply collapse, input transients, or thermal gradients. Those conditions require the [verification plan](VALIDATION.md).

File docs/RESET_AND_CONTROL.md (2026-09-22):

# Reset and Control

## ON, OFF, and STOP

An `ON` command performs configuration and discharge checks, sets U503 through U903's `RUN_SET` pulse, and enables the supplies. If the board is already running at the requested configuration, `ON` checks its state and returns without interrupting power or repeating the pulse. `OFF` disables both supplies and clears U503. STOP and the hardware protective clear path act independently of software. None of these actions changes the explicit DUT reset request retained by U903.

After verified command completion, the power state must survive Pico inactivity, USB disconnection, reboot, or complete Pico power loss while 12 V remains continuously valid and no hardware fault or STOP occurs. The Pico performs no periodic task to sustain power. A complete board input loss and discharge instead defaults OFF on return and requires a new checked `ON`. See [AUTONOMOUS_POWER.md](AUTONOMOUS_POWER.md) for the full contract.

After STOP or a latched protective trip, the supplies remain inhibited until a new `ON` command from the user or experiment script completes the startup checks. A released STOP button or cleared OVP condition cannot set U503 again. A fault latched inside the TPS259470L eFuse can require cycling the 12 V input; the controller cannot clear that internal latch through U503.

Intrinsic eFuse UVLO/OVLO is distinct from a latched protective trip: the eFuse can inhibit and recover its output while its fault pin remains inactive. Restoring the previous operating point requires both surviving control state and surviving regulator configuration. A partial brownout that resets PMBus registers while the latch remains set is not guaranteed to recover transparently. Loss of independent control power clears U503 and requires a new `ON`. U509 reports post-eFuse input undervoltage on `VIN12_VALID` for diagnostics and does not clear U503.

An explicit `SET` that changes feedback scale turns off the rail requests, verifies discharge, programs the new configuration, and restores the prior running requests only if the existing run latch survives throughout. It does not clear or repulse U503. STOP or a hardware fault during that interval clears the retained latch and blocks restart even if the fault later disappears; recovery requires a new `ON`. A SET while already OFF programs and reads back the new target while remaining OFF. Neither path inserts a reset pulse. Ordinary warnings do not become protective trips. A same-scale SET while ON does not cycle power. `STATUS`, `PING`, reconnecting the host, and fault recovery cannot set a cleared run latch.

Controller status reports `run_latch` and `hw_fault_n`; neither measures output voltage. A completed OFF returns U903 P04 `CLEAR_REQUEST` low after pulsing it high through Q901. A high clear request retained by an interrupted command continues to hold the fault bus low; that reading does not by itself identify an external fault.

## Controller interface

The [Pico firmware](../../controller/README.md) is maintained alongside this schematic package. Confirm the selected voltage range, assembly, calibration, and protective settings before enabling the DUT. A complete host application for kernel upload, JTAG result checking, and steady-power data acquisition is not included. The controller accepts one JSON request per USB serial line. Its only board-connected GPIO are GP0 SDA and GP1 SCL, through U902 ISO1640BDR; side 1 is board-powered and side 2 Pico-powered.

U903 TCA9535 at 7-bit address 0x20 supplies the retained control interface:

| U903 port | Signal | Function |
|---|---|---|
| P00 | `CORE_REQ` | Retained Core enable request |
| P01 | `IO_REQ` | Retained I/O enable request |
| P02 | `RESET_ASSERT` | Retained explicit reset request; high asserts, low releases |
| P03 | `RUN_SET` | One pulse during a checked startup; low after completion |
| P04 | `CLEAR_REQUEST` | High turns on Q901 to pull the fault bus low |
| P05 | `RUN_LATCH` | U503 state readback |
| P06 | `HW_FAULT_N` | Shared fault bus readback; low inhibits operation |
| P07 | `CORE_PG` | Core PG observation; diagnostic only |
| P10 | `IO_VALID` | Measured I/O-voltage qualifier; diagnostic only |
| P11 | `VIN12_VALID` | Post-eFuse input-voltage observation; diagnostic only |
| P12–P17 | `UNUSED_P12`–`UNUSED_P17` | Inputs, each pulled to ground through R1004–R1009 = 10 kΩ |

Q901 provides the clear pull-down; never drive `HW_FAULT_N` push-pull high. The bus is shared with STOP and the hardware fault detectors. U507 conditions it into `HW_CLEAR_N` for U503's asynchronous clear. Its other channel conditions `RUN_SET` into `RUN_SET_CLEAN` for U503's clock. R507 holds `RUN_SET` low before U903 is configured.

Pico boot and host reconnection first read existing state without rewriting outputs, direction registers, regulator settings, or reset requests. Cold U903 initialization is permitted only after confirming the board is OFF: write safe output values before output directions, because U903's power-on output register is 0xFF while its ports start as inputs. The exact register sequence is in [AUTONOMOUS_POWER.md](AUTONOMOUS_POWER.md).

An explicit `ON` startup from the OFF state must:

1. Hold U903 `CORE_REQ`, `IO_REQ`, and `RUN_SET` low. Preserve the explicit reset request. Pulse `CLEAR_REQUEST`, confirm `RUN_LATCH` is low, then release the clear request.
2. Confirm both outputs have discharged below 50 mV. Configure the selected operating point and protection settings with the outputs disabled, then verify register readback.
3. With `CLEAR_REQUEST` released, verify `HW_FAULT_N` remains high for 10 ms after hardware startup holdoff. If a hardware fault remains, report it and keep the outputs disabled.
4. Generate one 1 ms-high `RUN_SET` pulse, then return it low. Verify both `RUN_LATCH` and `HW_FAULT_N` are high before issuing the Core/I/O enable sequence.
5. Check final requests, latch state, and regulator readback before reporting success. A failed commissioning, discharge, configuration-readback, or latch check inhibits startup. Do not repeat the set pulse or automatically retry. Once established, independent hardware protects the rails without software monitoring; faults on the shared clear path disable both rails and require a new `ON` after the cause is resolved.

Normal `OFF` follows the configured reverse power sequence, attempts to confirm discharge, and clears the latch while preserving the explicit reset request. A successful OFF verifies that rail requests and the run latch are low; it does not prove zero measured voltage. Failed discharge or regulator/measurement access is reported in `off_verification` warnings. Check the measured rails for external back-power before handling the DUT. STOP and hardware clear act without waiting for this software sequence. A completed OFF stays OFF without Pico execution. If a command is interrupted before its writes and readbacks complete, its outcome is unknown: retained state may be intermediate. Reconnect with read-only observation, report the actual state, and require an explicit recovery command. Never replay a command or clear/reinitialize active outputs merely because the Pico rebooted.

## Warnings and protective trips

| Observation | Controller response |
|---|---|
| `CORE_PG`, `IO_VALID`, or `VIN12_VALID` low; ordinary undervoltage or voltage deviation | Report a warning when observed; leave power and reset requests unchanged |
| PMBus warning/status information, USB inactivity, malformed command, or measurement I2C/INA read failure | Report diagnostics when available; leave power and reset requests unchanged |
| Core current above the routine 8 A experiment budget or the 10 A continuous board target | Warn; these values are not automatic trip thresholds |
| I/O current above the 1 A provisioned budget | Warn; no arbitrary 1.5 A shutdown threshold is imposed |
| Programmed regulator OC/OV/OT condition | Regulator hardware performs its verified protective response without Pico service |
| STOP, board hardware OV/temperature trip, control brownout, or asserted eFuse fault | Hardware clears U503 and inhibits both rails; recovery requires a new `ON` |

U1001 independently trips at nominal 75°C with ±2°C sensor accuracy and nominal 5°C hysteresis. U1002 independently protects I/O at nominal 2.02446 V; its tolerance means this is not an exact 2.025 V ceiling. R1001 = 100 kΩ gives U502 a 180–420 ms startup holdoff, providing margin over the TMP302 datasheet §9 statement of functional readiness within 35 ms after VS reaches 1.4 V. Hot-start and supply-ramp qualification of the assembled circuit is still required. Regulator relative OVP is configured at 112.5% of target, with commissioned 15 A OC and internal OT protection; approximately 1.319 V Core hardware OVP remains separate. The former software 14 A/100 ms guard is not an autonomous hardware timing guarantee. These are fixture settings, not measured ASIC absolute-maximum ratings. On-demand warnings and raw PMBus status aid interpretation but are not a continuous event log.

## DUT reset

J1.54 is a 1.8 V, active-high reset input. R602 is its 10 kΩ pull-up to VIO. Q601, an MMBT3904 with B/E/C on pins 1/2/3, releases reset by pulling the node low. R603 = 21.5 kΩ biases its base from VIO, and R604 = 100 kΩ connects the base to ground. With valid VIO and no reset request, Q601 conducts and reset is released without firmware execution.

SW601, U601, and Q602 each pull `RESET_BASE` low to assert reset. Q602 is a DMN62D2UQ-7: gate pin 1 connects to U903 P02 `RESET_ASSERT`, source pin 2 to ground, and drain pin 3 to `RESET_BASE`. R411 = 100 kΩ holds its gate low when U903 is uninitialized or unpowered. U903 high asserts the explicit request; low releases it. Once set, the request survives Pico reboot or absence. `RUN_LATCH`, PG, voltage qualifiers, and automatic power sequencing have no reset-control function. The high reset level depends on VIO; no valid logic level is promised during its collapse. The control request is retained, but there is no automatic event capture, minimum pulse-width circuit, or clock synchronizer.

Manual, remote, or commanded reset can be repeated while the rails remain enabled. The explicit Pico commands are `{"cmd":"RESET","assert":true}` and `{"cmd":"RESET","assert":false}`. Only explicit RESET commands change the initialized retained request; `ON`, `OFF`, `SET`, Pico reconnection, warnings, and protective shutdown preserve it. `reset_asserted` in status describes the U903 request, not a measurement of the pin or manual/remote inputs. Releasing one request cannot override another asserted request. Reset does not clear the run latch. STOP clears the latch and disables the rails.

## Remote connector

J602 connects to the input LED of U601, `TLP293(GB-TPL,E`, through R605 = 750 Ω.

| Pin | Net | Connection |
|---|---|---|
| 1 | ZED_3V3 | ZedBoard Pmod 3.3 V, for example JA pin 6 |
| 2 | ZED_RESET_OD | ZedBoard GPIO configured for low or high impedance, for example JA pin 1 |

Pin 2 is a GPIO return for the optocoupler LED, not ground. Use two male-to-female leads and verify connector orientation against the ZedBoard revision. Do not supply this input from the Sphinx 3.3 V rail. Account for the 200 Ω series resistor on the applicable ZedBoard Pmod signal.

A low GPIO asserts reset. High impedance releases the remote request. Disable internal pull-down and keeper functions. The input circuit has no conductive connection to Sphinx power or ground; other interfaces, including JTAG, can connect the board grounds.

U601 output emitter pin 3 connects to Sphinx ground and collector pin 4 to `RESET_BASE`, in parallel with SW601 and Q602. Verify reset levels and optocoupler delay over the intended supply and temperature range.

## Procedure

1. Connect the supply, clock source, and 1.8 V JTAG interface with outputs inactive.
2. Apply 12 V and complete controller commissioning. The board starts OFF; attaching USB does not start or reset it. Select the Core operating point and issue one `ON`, then wait for verified completion. The command checks configuration, sets the run latch, and enables Core and I/O without resetting the DUT. The established supply state then persists without continued Pico execution.
3. Once supplies are valid, run the external clock and establish JTAG communication.
4. Explicitly assert reset with SW601, J602, or the Pico `RESET` command. Keep the clock running throughout the reset interval. Use a comfortably long pulse; minimum-cycle operation is not required.
5. Release reset asynchronously and begin testing. Repeat reset as required during the experiment.
6. For functionality, load and run one kernel, then read and compare its output. For power, run a large back-to-back loop, allow electrical and thermal readings to settle, and request averaged voltage, current, and power together with warning/status and clock settings. PMBus is at 0x10; Core/I/O INA226 at 0x40/0x41; retained controls at 0x20; NTC telemetry at 0x48. These measurements do not keep the rails alive. Reconnect a lost Pico or USB link with read-only state discovery before further commands.
7. For shutdown, stop or tri-state external signal drivers before I/O power falls, issue `OFF`, and confirm discharge. An intentional reset before shutdown is optional and must be requested explicitly with power and clock valid; `OFF` never inserts it.

Remote reset does not replace explicit power commands or independent hardware protection. If a command is interrupted, read back the state before deciding whether to continue or issue recovery.

## Measurement

Probe TP7 against TP607 to observe reset at J1.54. Use a high-impedance, low-capacitance probe with a short ground connection. Do not use a 50 Ω termination. Include probe capacitance when measuring the 10 kΩ pull-up edge.

Capture Core, I/O, `CORE_PG` or `IO_VALID`, and reset together during kernel transitions. Verify that ordinary power-qualification changes do not generate a reset pulse. Software polling is not a record of every short pin event. Record the regulator status registers separately from observed waveforms; steady-loop INA226 telemetry serves the averaged-power experiment, while the oscilloscope checks transient supply behavior.

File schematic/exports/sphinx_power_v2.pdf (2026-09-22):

1 | 2 | 3 | 4 | 5 | 6 | 7 | 8

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
Size: A3 | Rev: V2 | F Date: 2026-09-22
KiCad E.D.A. 10.0.5 | Id: 1/11

# Title: Sphinx V2 | Programmable power test platform

## File: sphinx_power_v2.kicad_sch

## Sheet: /

## Sphinx | Programmable power test board

## Review package: PCB, PI, SI, thermal and ASIC limits require qualification

## 12 V nominal input | VCORE 0.30-1.20 V | VIO 1.80 V

## Author: Yuchen Mei

Protected input and auxiliary supply

File: 01_input_aux.kicad_sch Fixed 1.8 V I/O and calibrated telemetry

File: 03_io_and_telemetry.kicad_sch Distributed core decoupling and test access

File: 07_core_decoupling.kicad_sch 09 | Independent control supply and retained board state

File: 09_autonomous_control.kicad_sch

PMBus core regulator, 0.30-1.20 V

File: 02_core_regulator.kicad_sch USB control and remote reset File: 04_usb_control.kicad_sch Hardware power shutdown latch

File: 05_hardware_safety.kicad_sch | Socket pinout and signal interfaces

File: 06_socket_and_signals.kicad_sch

I/O decoupling and voltage monitor File: 08_io_decoupling.kicad_sch 10 | Independent temperature and IO overvoltage protection
File: 10_independent_protection.kicad_sch | #FLG8 PWR_FLAG

#FLG7 PWR_FLAG

#FLG6 PWR_FLAG

#FLG5 PWR_FLAG

#FLG1 PWR_FLAG

#FLG3 PWR_FLAG

#FLG9 PWR_FLAG

#FLG10 PWR_FLAG

#FLG2 PWR_FLAG

GND | VIN_RAW | VIN_FUSED | AUX5V | PICO_VSYS | 0V75 | 1V8 | CORE_DRTN | CORE_AVIN

Independent board control power. Pico is command-only; held supply and reset state survives Pico loss. Functionality: one kernel execution. Power: back-to-back loop, then read steady-state rail V/I/P. 10 A continuous design target. Characterize voltage, frequency, power, and temperature per DUT. Change feedback scale with outputs disabled. Layout requirements: docs/LAYOUT_HANDOFF.md. 12 V input, eFuse, PMBus core regulator, current shunt, socket VCORE; fixed 1.8 V I/O.

Core/I/O telemetry; Pico USB control; 12+12 capacitor population; hardware power shutdown latch and STOP. Valid VIO: reset defaults released; explicit button/ZedBoard/Pico reset only. PG and VIN12_VALID are monitors.

Core: 0.75 V nominal, 5 W active, 1 GHz target. Range: 0.30-1.20 V. I/O: 1.8 V. Schematic for PCB layout.

# SPHINX V2 - PROGRAMMABLE CORE POWER

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
# Title: 01 | Protected input and auxiliary supply

## File: 01_input_aux.kicad_sch

## Sheet: /Protected input and auxiliary supply/

## Sphinx | Programmable power test board

## Review package: PCB, PI, SI, thermal and ASIC limits require qualification

## 12 V nominal input | VCORE 0.30-1.20 V | VIO 1.80 V

## Author: Yuchen Mei L101

10u / SRP7028A

C103

10n / 50V | C104
22u / 25V R102

10k R101

78.7k | C105
1u / 50V R103

110k C102
100n / 100V

R107
73.2k GND 1 | SW | 2 VIN 3 | FB | 4 EN 5 | BOOT | 6 U102
TPS54302DDCR

C101
1u / 50V | R104
10k | R108

10k

EN/UVLO 1 | OVLO 2 | AUXOFF | 3 FLT_N | 4
IN 5 | OUT | 6 DVDT | 7 GND 8
ILM | 9
ITIMER | 10 U101
TPS259470LRPWR

C109
22u / 10V

R105
1.24k / 1%

C108
22u / 10V

F101
3.15A / 63V CONTACT | 1 CONTACT | 2

J102
24.243.2 BLACK

C106
10u / 35V X7R

C107
100n / 100V
CONTACT | 1 CONTACT | 2

J101
24.243.1 RED

AUX5V

GND

AUX_SW

AUX_SW

INPUT_UVLO

AUX_BOOT

VIN_FUSED

AUX5V | GND

GND

AUX5V GND

VIN12 | GND

GND

GND

GND

VIN_FUSED | HW_FAULT_N

VIN_FUSED

INPUT_UVLO

INPUT_OVLO

VIN12

INPUT_UVLO

AUX_FB

GND

AUX_FB

GND

GND

INPUT_OVLO

GND

AUX_BOOT

INPUT_OVLO

VIN_FUSED

VIN_FUSED

AUX5V

VIN12

AUX_FB

GND

AUX_SW

VIN_RAW

INPUT_DVDT | VIN12

INPUT_ILM

GND

GND

VIN12

VIN_RAW

GND

VIN_FUSED

INPUT_ILM | INPUT_DVDT

VIN_RAW

AUX5V = 0.596*(1+73.2k/10k) = 4.959 V nominal. U102 EN intentionally floating (internal enable).

F101 is backup protection. U101 UVLO/OVLO auto-recover; U509 VIN12_VALID is monitor-only.

J101: +12 V supply positive. J102: GND / supply negative. Each socket: BOTH pads are common. Use two full-current supply leads.

U101 OUT connects directly to VIN12. Measure input current externally.

ILM connects only to local R105. INPUT: use 12 V / 3 A bench supply. OVLO disconnects a steady 20 V mis-setting.

Use 12V nominal; terminal target11.5-13V. Intrinsic UVLO interrupts power; eFuse FLT/control brownout can clear RUN_LATCH. UVLO about 10.6 V rising; OVLO about 14.4 V rising. ILIM about 2.69 A (device tolerance applies).

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
# Title: 02 | PMBus core regulator, 0.30-1.20 V

## File: 02_core_regulator.kicad_sch

## Sheet: /PMBus core regulator, 0.30-1.20 V/

## Sphinx | Programmable power test board

## Review package: PCB, PI, SI, thermal and ASIC limits require qualification

## 12 V nominal input | VCORE 0.30-1.20 V | VIO 1.80 V

## Author: Yuchen Mei

L201
0.56u / XAL1030 | R203

1R / 0.25W

R209
4.64k / 1%

R208
12.1k / 1%

C206

22u / 25V | C207

22u / 25V C205
22u / 25V R207

10k R206
19.6k R205

21.5k

C203

1u / 10V C201

100n / 100V | R201
| 1m / 1W KELVIN

C202

4.7u / 16V | C210

# 1n / 50V C209

4.7n / 25V C208
22u / 25V

R212
47R / 0.5W

R202
10R

R210

100k | R211

10k C204
1u / 50V
PGD | 1 PMB_DATA 2 | PMB_CLK 3 | BP1V5 4 | DRTN 5 | SMB_ALRT_N 6 | BOOT | 7 SW | 8 PGND/AGND/EP | 13
PVIN 21 | AVIN 26 | EN/UVLO 27 | VDD5 | 28 MSEL2 29 | VSEL 30 | ADRSEL 31 | MSEL1 32 | VOSNS | 33 GOSNS | 34 VSHARE | 35 SYNC | 38 BCX_CLK | 39 BCX_DAT | 40

U201
TPS546B24ARVFR

R204
12.1k MSEL1
CORE_BOOT | GND

VIN12 PMBUS_SCL CORE_ALERT_N MSEL1 MSEL2

VIN12

VSEL | GND
ADRSEL CORE_BP1V5 | MSEL2

CORE_DRTN

GND

GND

GND

GND

# CORE_BP1V5 MSEL2

CORE_PG

GND

CORE_SENSE_N

CORE_SENSE_P

CORE_PRE_SHUNT

CORE_BP1V5 MSEL1 | GND

CORE_VDD5

GND

3V3_CTRL CORE_AVIN

CORE_PG

VSEL | GND

GND

ADRSEL

0V75

VIN12

CORE_BOOT | GND

CORE_AVIN

VIN12 CORE_BP1V5 PMBUS_SDA

VIN12 CORE_DRTN

CORE_EN

GND

GND

CORE_SNUB

VIN12

CORE_AVIN

GND

0V75 CORE_SW

GND

CORE_EN

CORE_SNUB

CORE_VDD5

VIN12 | CORE_SW

CORE_SW

GND

BCX_CLK/DAT and NC pin36 grounded for stand-alone operation. AGND37 and all PGND/EP pads share local return. PMBus 7-bit address: 0x10. R209 = 4.64k to GND, no top resistor; SYNC auto-detect. Firmware must match.

Select 12+12 or 16+16 population; program and read back B1 with output OFF. Feedback scales: 1 and 0.5. DRTN connects ONLY to C203 negative. Do not short DRTN to board GND.

Boot 0.750 V. 650 kHz. Differential sense after R201 at socket. Output remains disabled until hardware run latch + retained board enable. 0.75 V nominal core; approximately 5 W during kernel execution. Board continuous-current design target: 10 A.

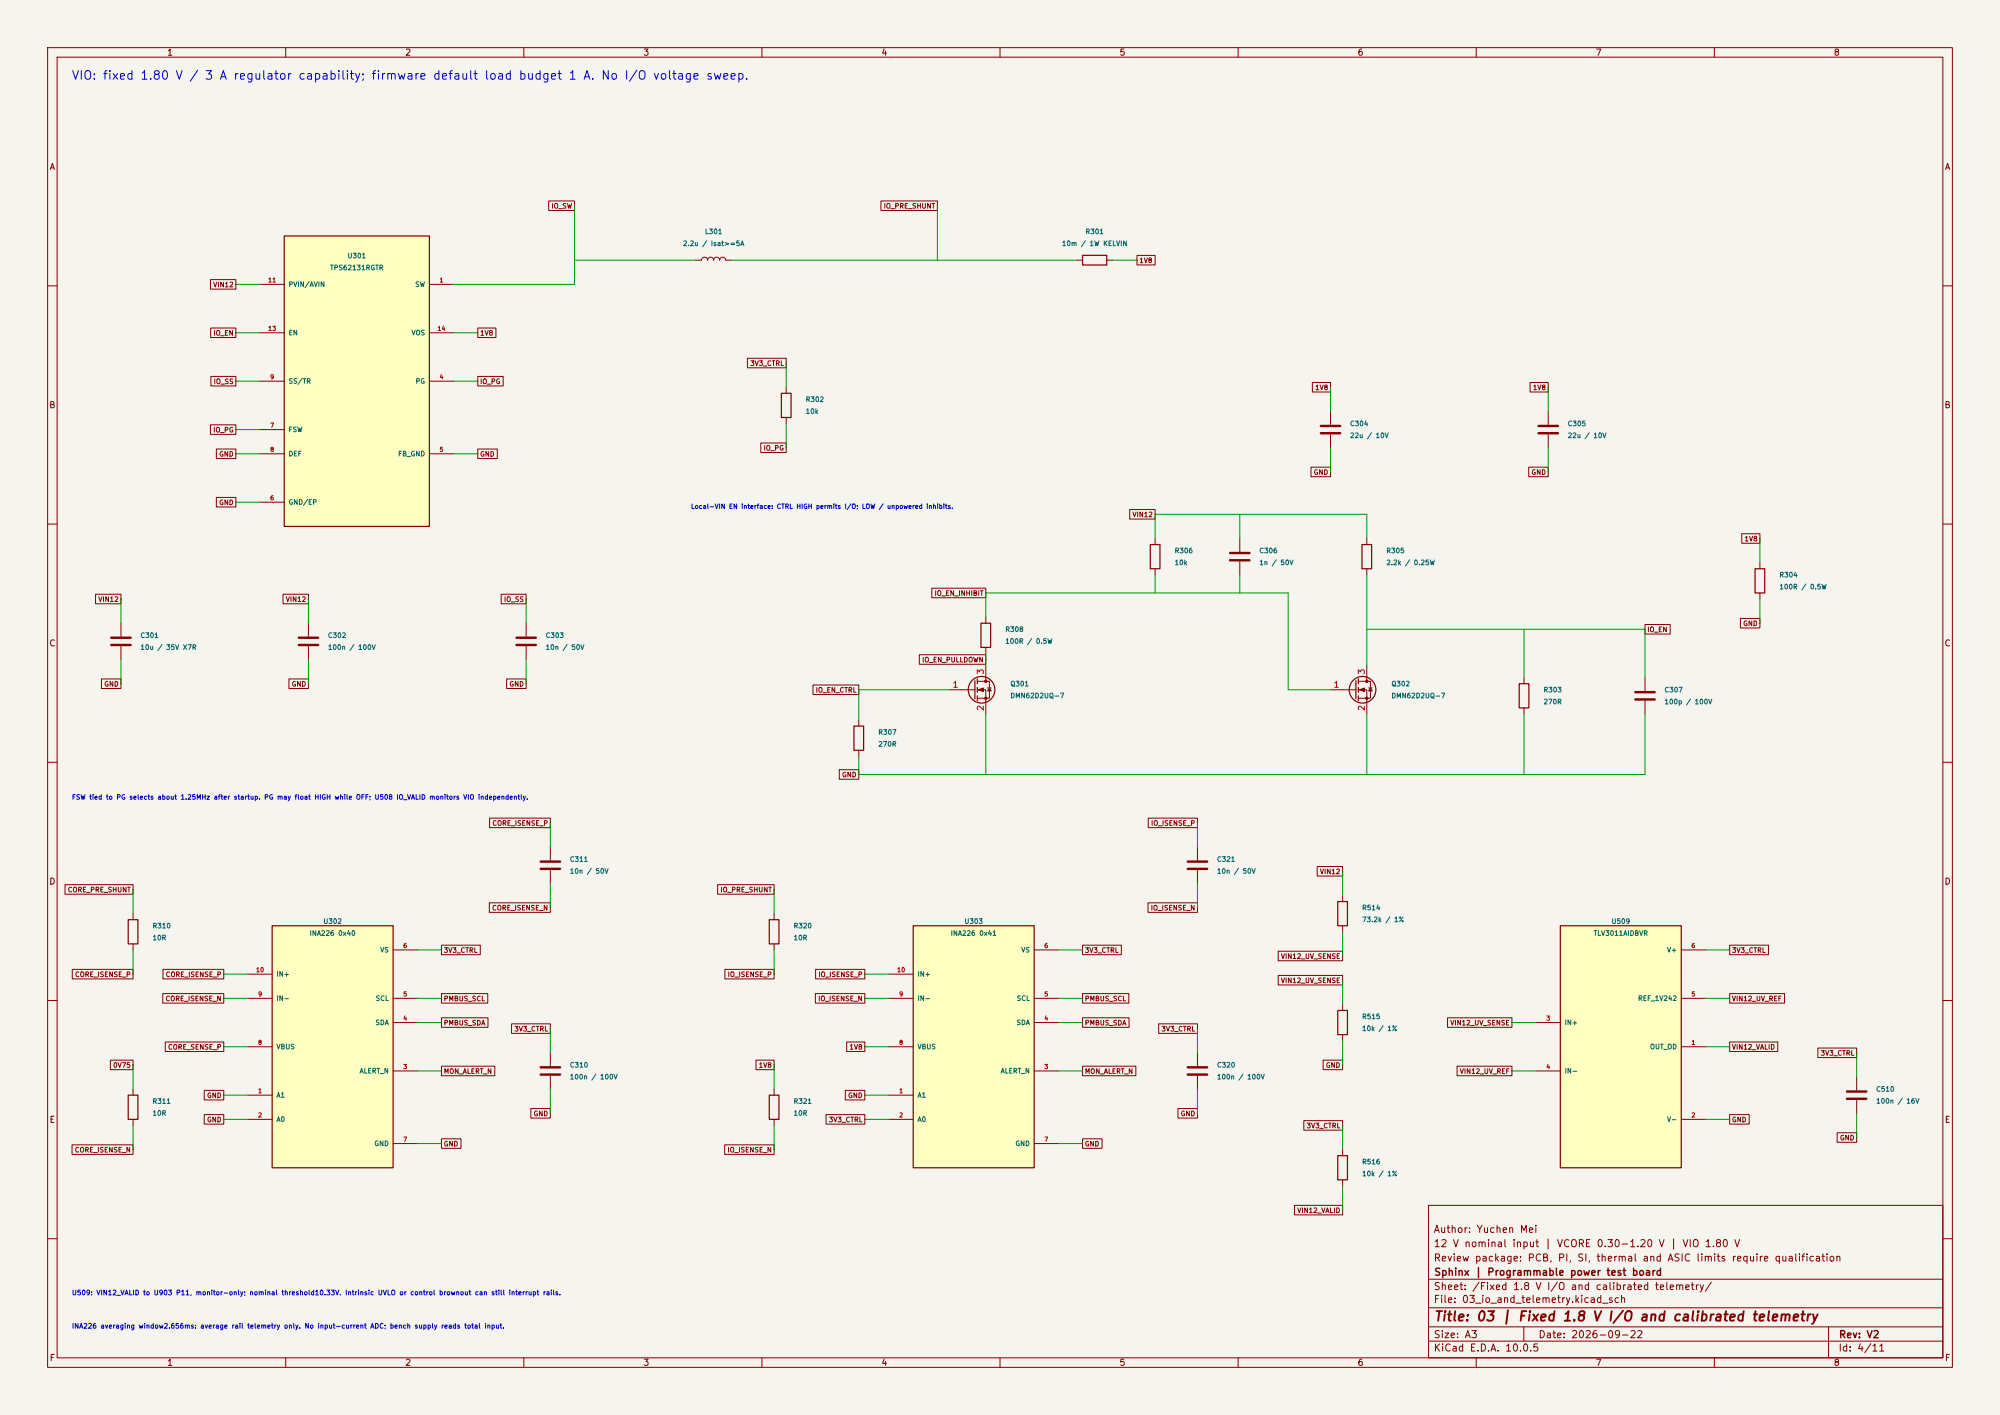
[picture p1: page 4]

VIO: fixed 1.80 V / 3 A regulator capability; firmware default load budget 1 A. No I/O voltage sweep.

Local-VIN EN interface: CTRL HIGH permits I/O; LOW / unpowered inhibits. FSW tied to PG selects about 1.25MHz after startup. PG may float HIGH while OFF; U508 IO_VALID monitors VIO independently.

Author: Yuchen Mei
12 V nominal input | VCORE 0.30-1.20 V | VIO 1.80 V
Review package: PCB, PI, SI, thermal and ASIC limits require qualification
Sphinx | Programmable power test board
Sheet: /Fixed 1.8 V I/O and calibrated telemetry/
File: 03_io_and_telemetry.kicad_sch
Title: 03 | Fixed 1.8 V I/O and calibrated telemetry

U509: VIN12_VALID to U903 P11, monitor-only; nominal threshold10.33V. Intrinsic UVLO or control brownout can still interrupt rails.

INA226 averaging window2.656ms: average rail telemetry only. No input-current ADC; bench supply reads total input.

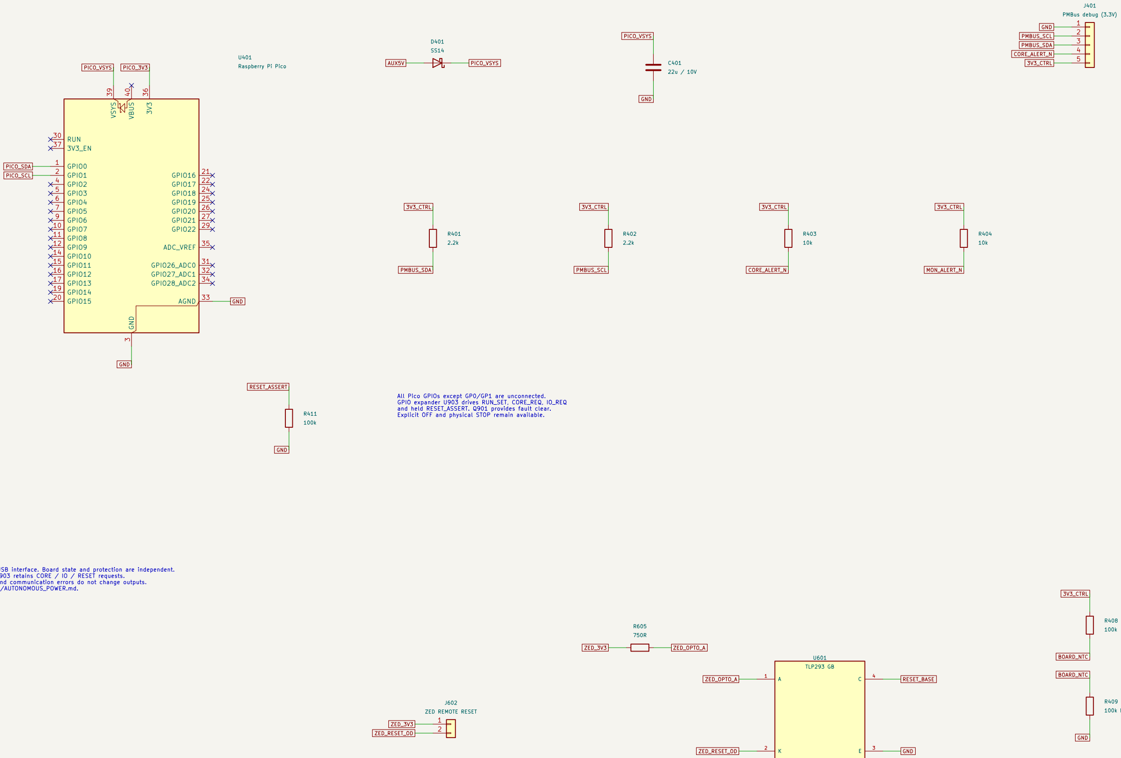
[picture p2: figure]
J401 PMBus debug (3.3V) R404; TLP293 GB; GPIO0 1; GPIO1 2; GND; AGND; 33 GPIO28_ADC2; ADC_VREF; VSYS 39; VBUS 40; U401 Raspberry Pi Pico; ZED_OPTO_A; 3V3_CTRL RESET_ASSERT; ZED_3V3; PICO_3V3; BOARD_NTC; 3V3_CTRL RESET_BASE; ZED_RESET_OD; 3V3_CTRL; CORE_ALERT_N; AUX5V; PMBUS_SDA PICO_VSYS; PMBUS_SCL; PICO_VSYS; MON_ALERT_N; PICO_SCL; 3V3_CTRL PICO_VSYS; PMBUS_SDA; 3V3_CTRL PMBUS_SCL; PICO_SDA

AB

C

D

E

AB

C

D

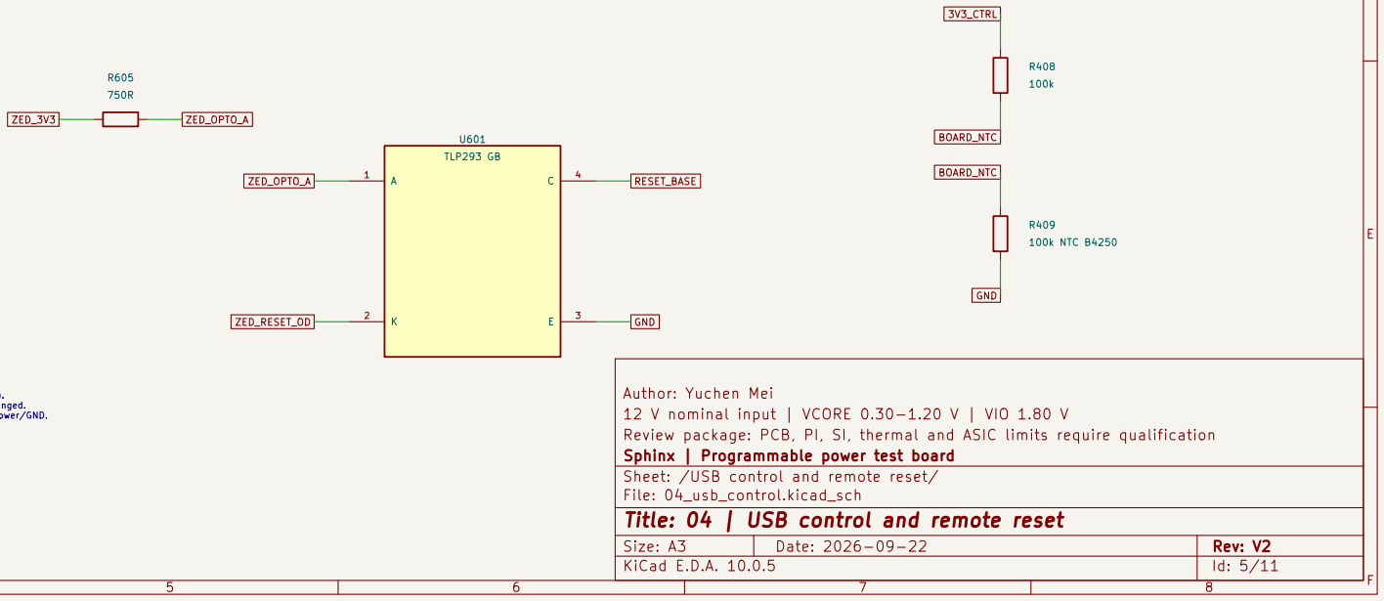
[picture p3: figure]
File: 04_usb_control.kicad_sch; Sheet: /USB control and remote reset/; Sphinx | Programmable power test board; Author: Yuchen Mei; 100k NTC B4250 R408

# Title: 04 | USB control and remote reset

## Review package: PCB, PI, SI, thermal and ASIC limits require qualification

## 12 V nominal input | VCORE 0.30-1.20 V | VIO 1.80 V

1
2

J602
ZED REMOTE RESET

3 GPIO2 4 GPIO3 5 GPIO4 6 GPIO5 7 GPIO6 9 GPIO7 10 GPIO8 11 GPIO9 12 GPIO10 14 GPIO11 15 GPIO12 16 GPIO13 17 GPIO14 19 GPIO15 20 GPIO16 21 GPIO17 22 GPIO18 24 GPIO19 25 GPIO20 26 GPIO21 27 GPIO22 29 RUN 30 GPIO26_ADC0 31 GPIO27_ADC1 32

J602: 1 = Zed Pmod3.3V; 2 = Zed GPIO LOW/Z (NOT GND). LOW asserts reset; Z/unplugged leaves local control unchanged. No conductive connection from either input pin to board power/GND.

USB commands: SET / ON / OFF / RESET / STATUS. Hardware controls: STOP and DUT RESET; reset is explicit only.

All Pico GPIOs except GP0/GP1 are unconnected. GPIO expander U903 drives RUN_SET, CORE_REQ, IO_REQ

and held RESET_ASSERT. Q901 provides fault clear. Explicit OFF and physical STOP remain available. Pico is a command-only USB interface. Board state and protection are independent.

I2C is isolated by U902; U903 retains CORE / IO / RESET requests. Pico boot, USB inactivity and communication errors do not change outputs. See sheets09/10 and docs/AUTONOMOUS_POWER.md.

Raspberry Pi Pico module: USB CDC + MicroPython controller; no proprietary USB/PMBus adapter required.

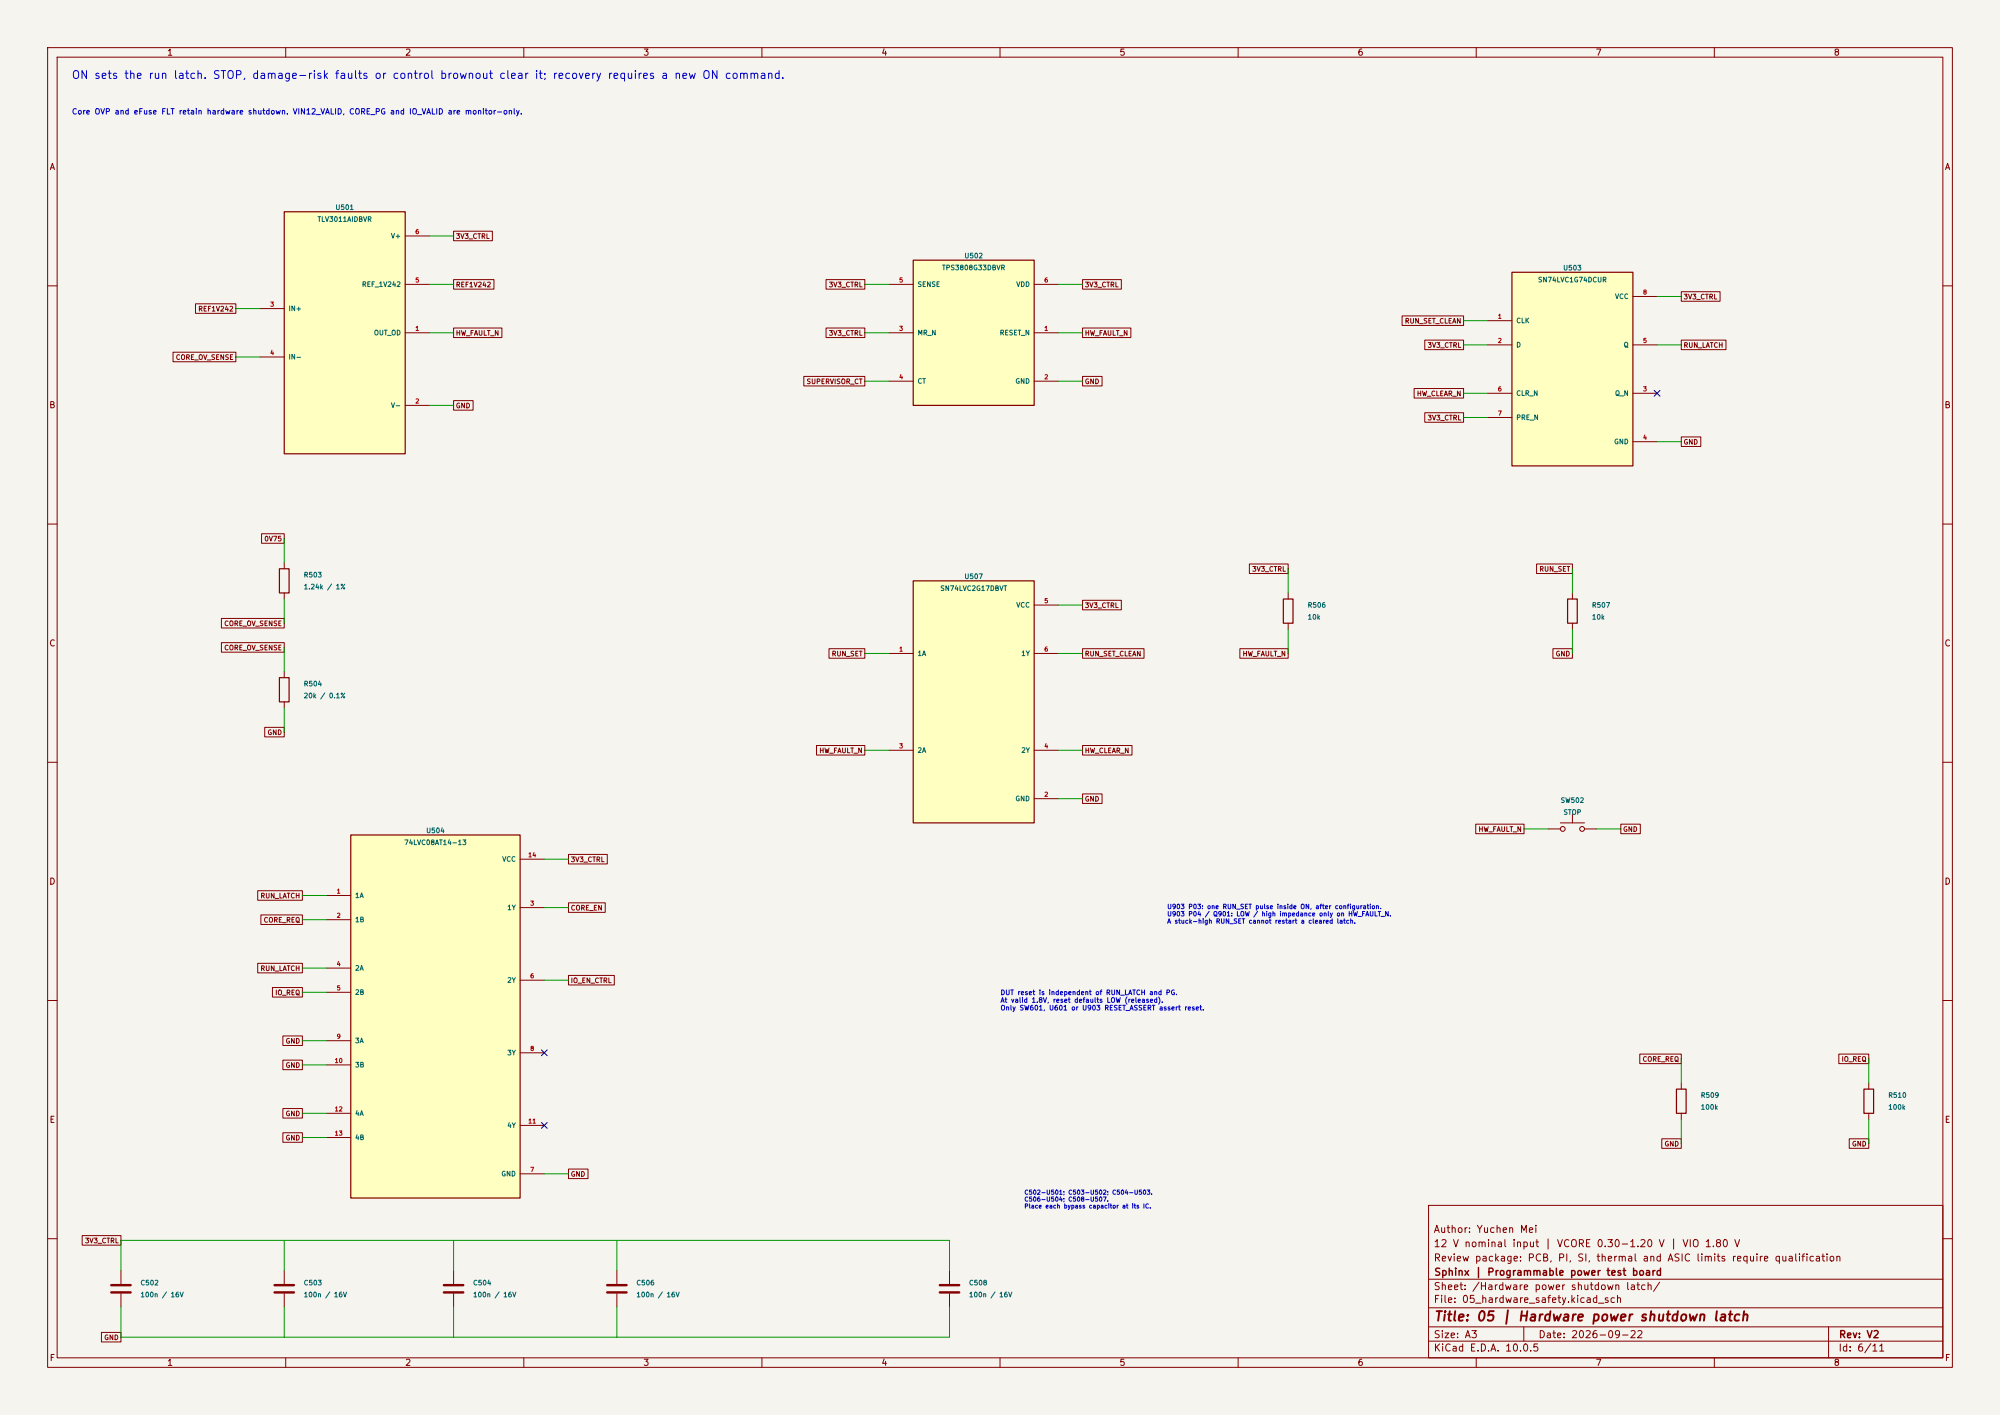
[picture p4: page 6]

ON sets the run latch. STOP, damage-risk faults or control brownout clear it; recovery requires a new ON command.

Core OVP and eFuse FLT retain hardware shutdown. VIN12_VALID, CORE_PG and IO_VALID are monitor-only.

C502-U501; C503-U502; C504-U503. C506-U504; C508-U507. Place each bypass capacitor at its IC. DUT reset is independent of RUN_LATCH and PG. At valid 1.8V, reset defaults LOW (released). Only SW601, U601 or U903 RESET_ASSERT assert reset. U903 P03: one RUN_SET pulse inside ON, after configuration. U903 P04 / Q901: LOW / high impedance only on HW_FAULT_N. A stuck-high RUN_SET cannot restart a cleared latch.

Author: Yuchen Mei
12 V nominal input | VCORE 0.30-1.20 V | VIO 1.80 V
Review package: PCB, PI, SI, thermal and ASIC limits require qualification
Sphinx | Programmable power test board
Sheet: /Hardware power shutdown latch/
File: 05_hardware_safety.kicad_sch
Title: 05 | Hardware power shutdown latch

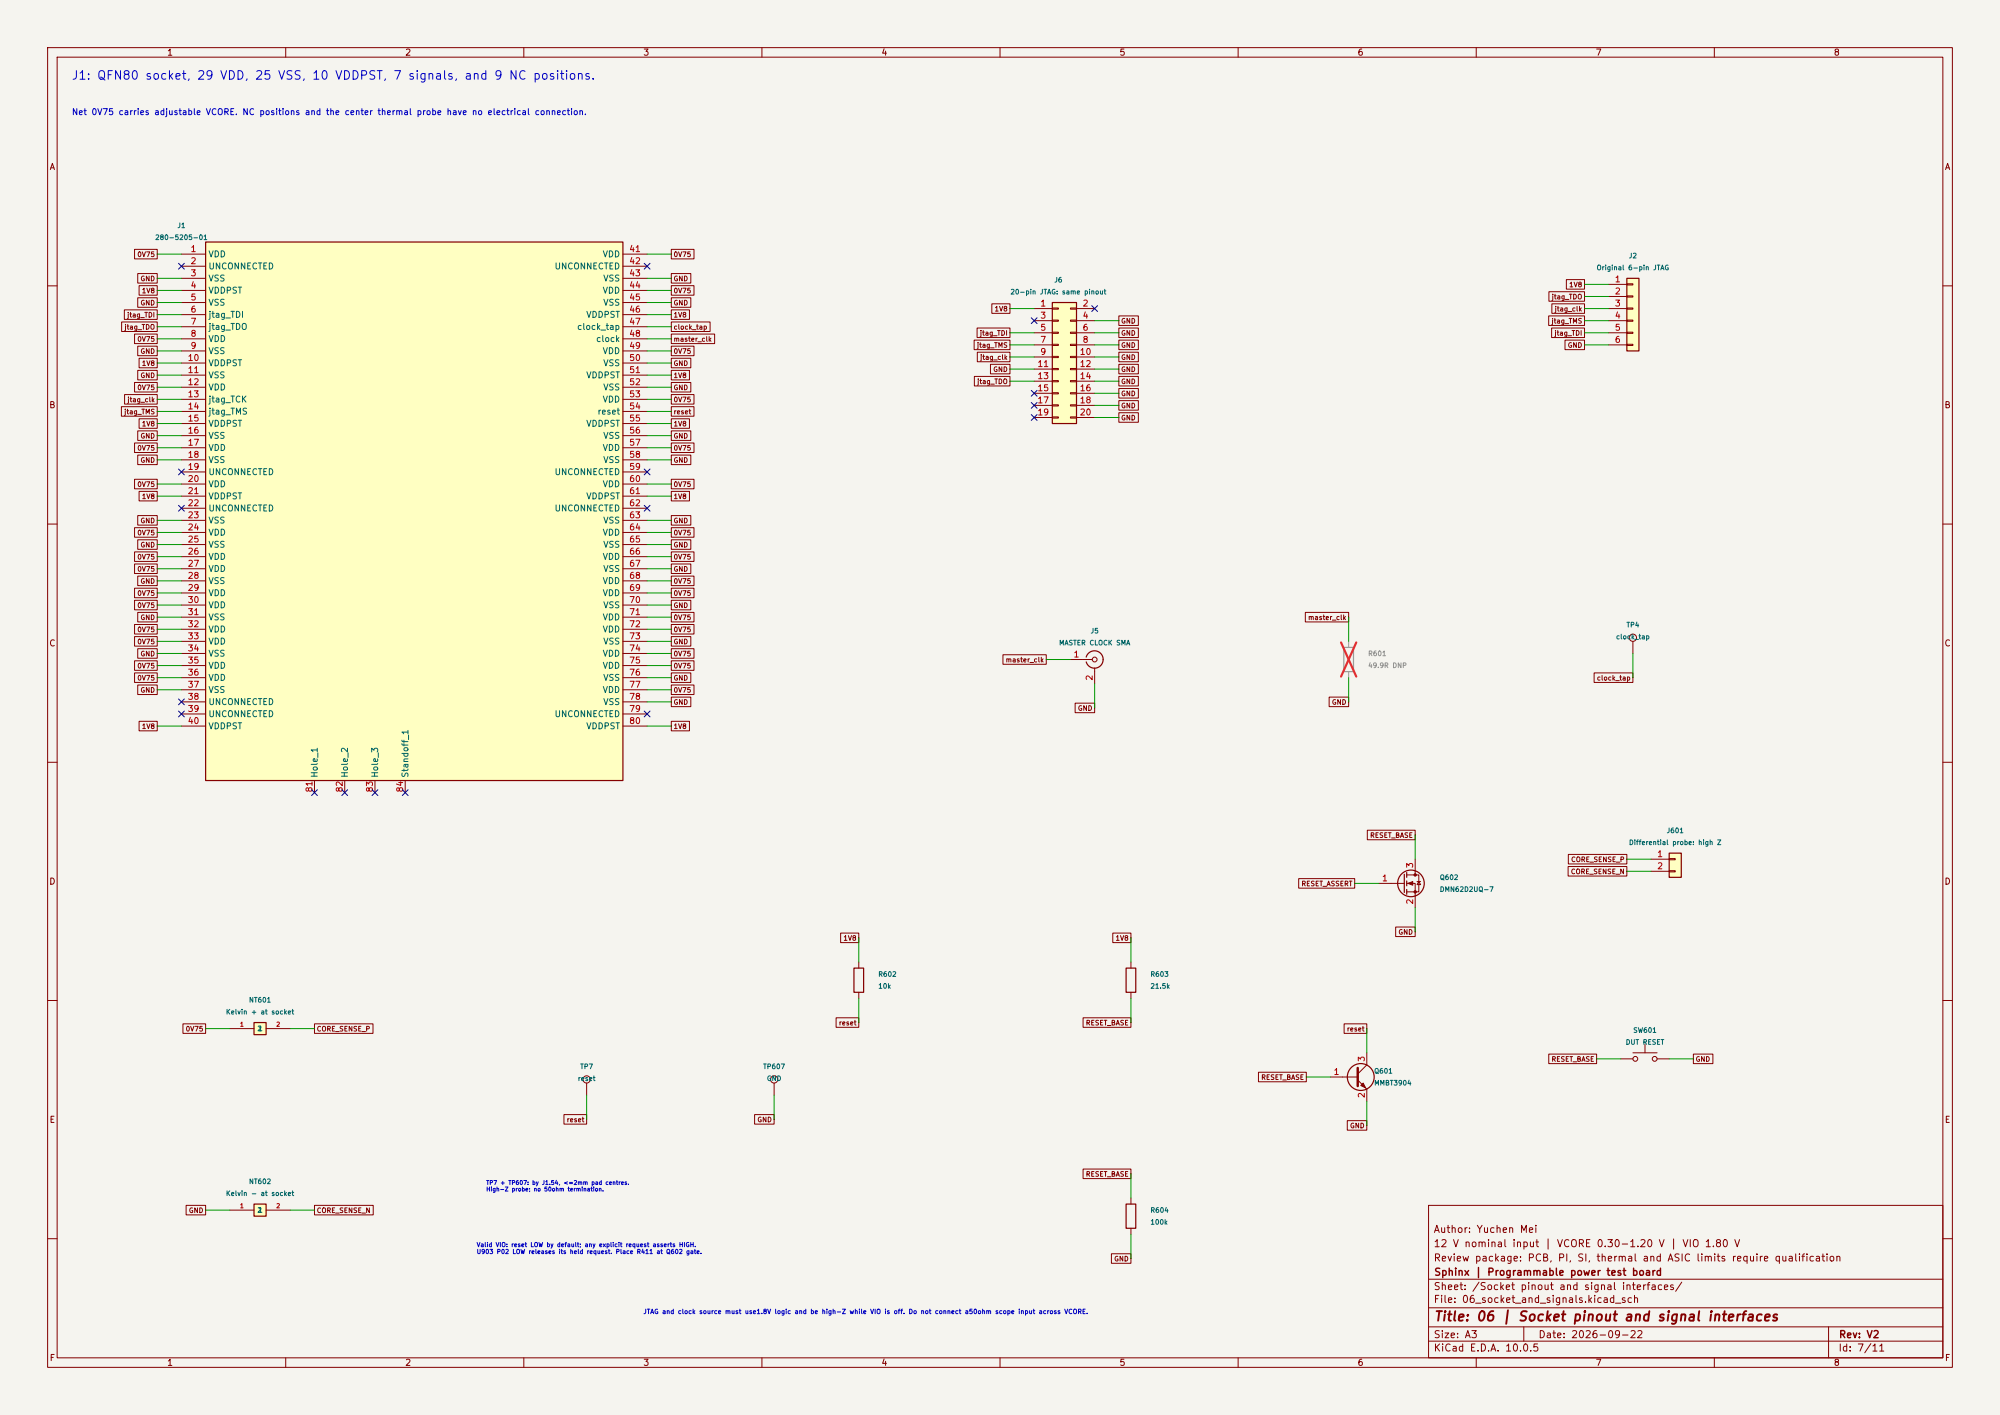
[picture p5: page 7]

J1: QFN80 socket, 29 VDD, 25 VSS, 10 VDDPST, 7 signals, and 9 NC positions. Net 0V75 carries adjustable VCORE. NC positions and the center thermal probe have no electrical connection.

20-pin JTAG: same pinout

JTAG and clock source must use1.8V logic and be high-Z while VIO is off. Do not connect a50ohm scope input across VCORE. Valid VIO: reset LOW by default; any explicit request asserts HIGH. U903 P02 LOW releases its held request. Place R411 at Q602 gate. TP7 + TP607: by J1.54, <=2mm pad centres. High-Z probe; no 50ohm termination.

Author: Yuchen Mei
12 V nominal input | VCORE 0.30-1.20 V | VIO 1.80 V
Review package: PCB, PI, SI, thermal and ASIC limits require qualification
Sphinx | Programmable power test board
Sheet: /Socket pinout and signal interfaces/
File: 06_socket_and_signals.kicad_sch
Title: 06 | Socket pinout and signal interfaces

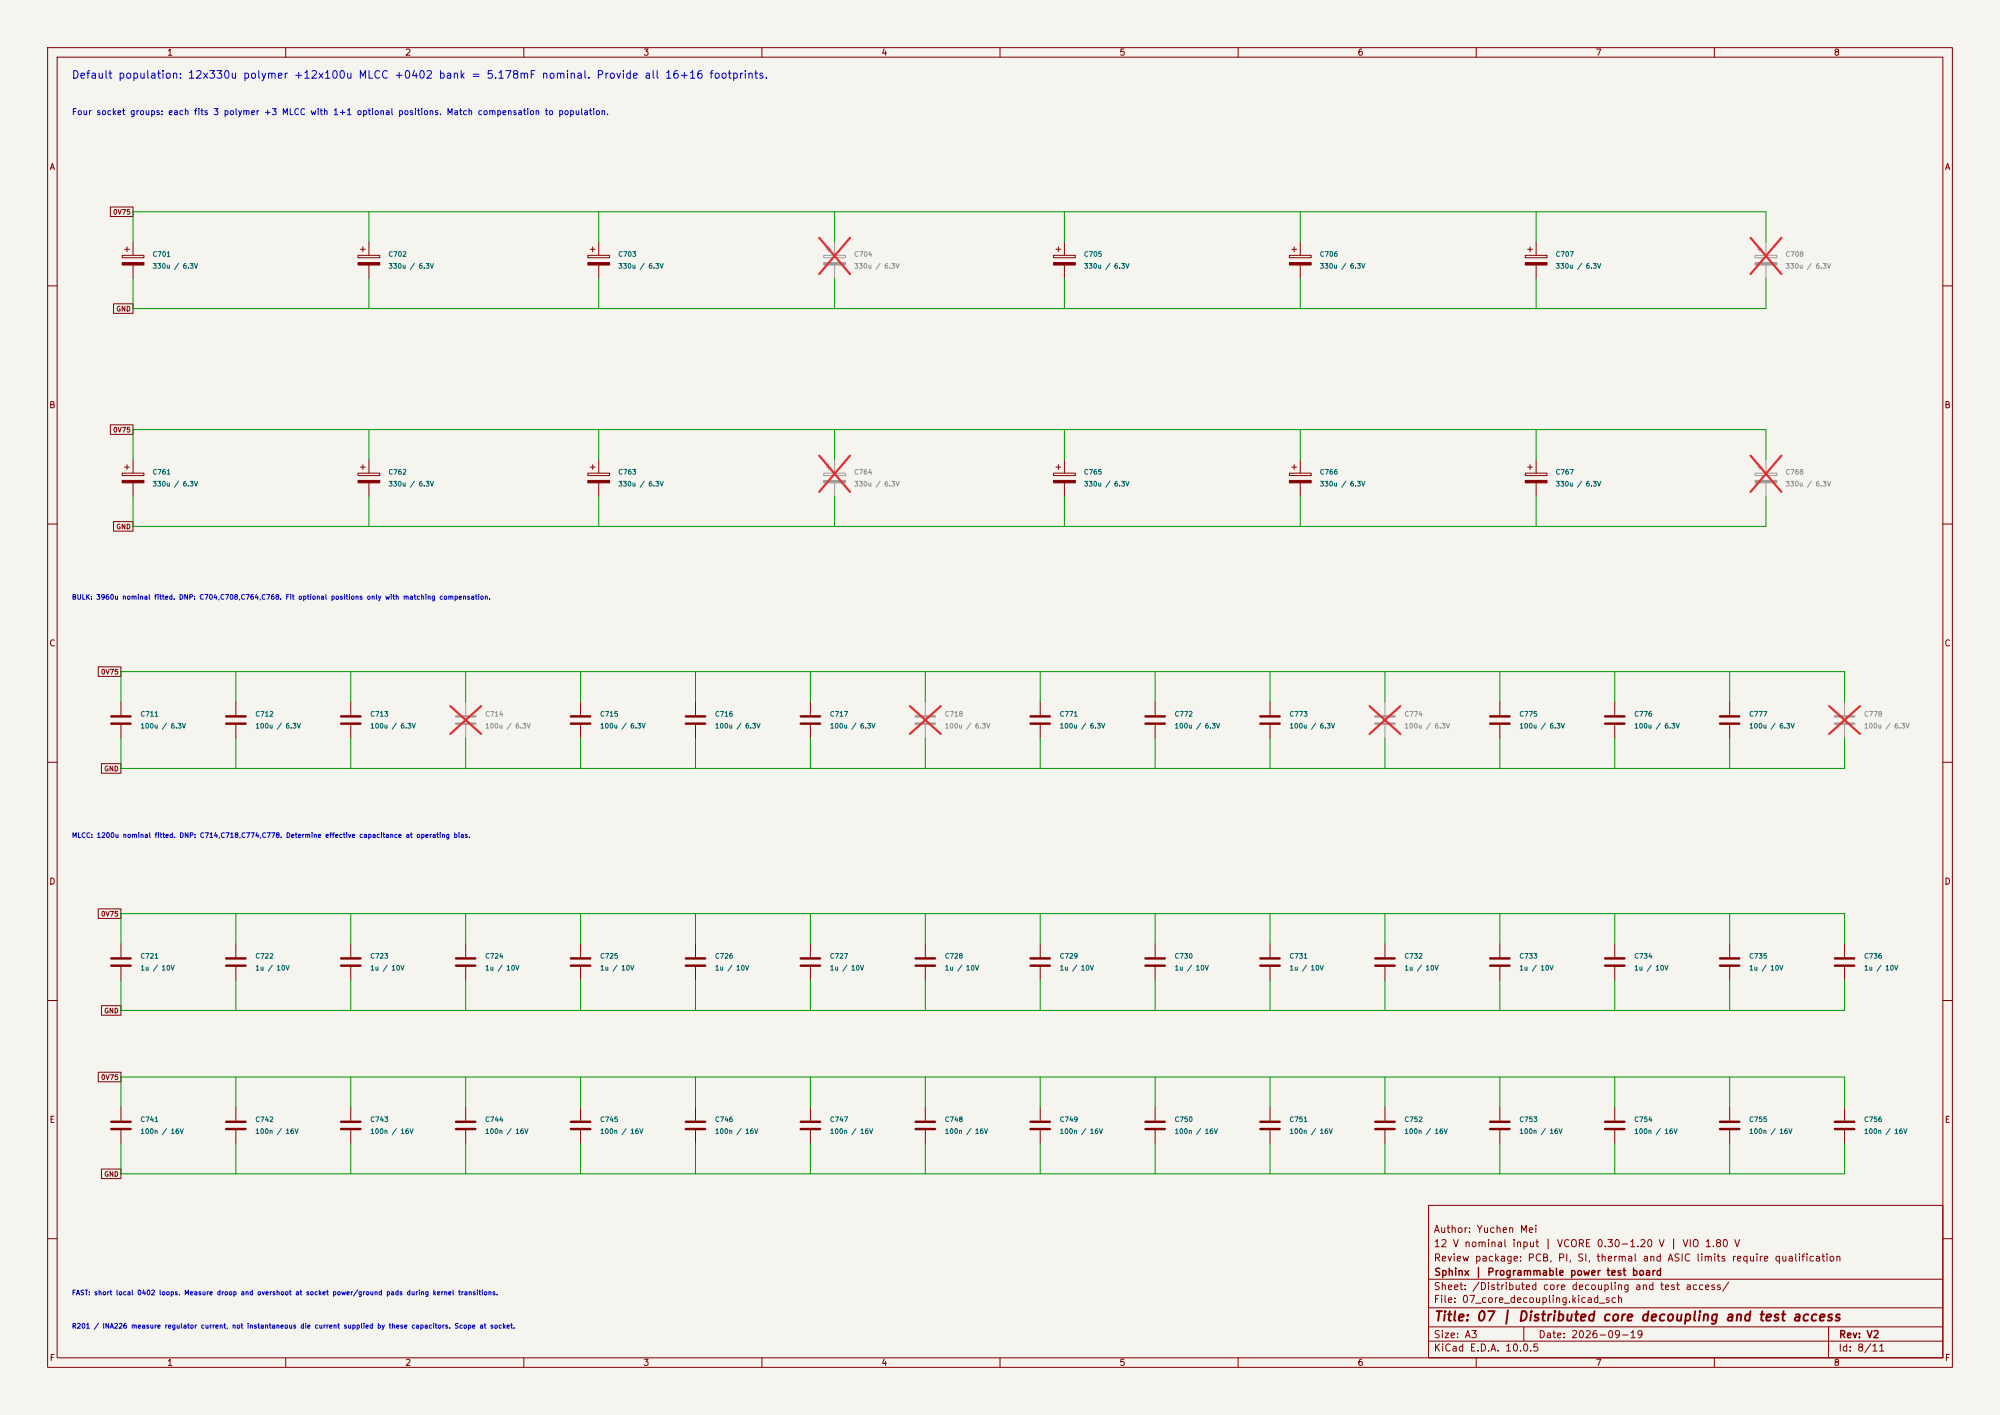
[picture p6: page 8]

Default population: 12x330u polymer +12x100u MLCC +0402 bank = 5.178mF nominal. Provide all 16+16 footprints.

Four socket groups: each fits 3 polymer +3 MLCC with 1+1 optional positions. Match compensation to population.

GND MLCC: 1200u nominal fitted. DNP: C714,C718,C774,C778. Determine effective capacitance at operating bias. BULK: 3960u nominal fitted. DNP: C704,C708,C764,C768. Fit optional positions only with matching compensation.

12 V nominal input | VCORE 0.30-1.20 V | VIO 1.80 V
Review package: PCB, PI, SI, thermal and ASIC limits require qualification
Sphinx | Programmable power test board
Sheet: /Distributed core decoupling and test access/
File: 07_core_decoupling.kicad_sch
Title: 07 | Distributed core decoupling and test access

R201 / INA226 measure regulator current, not instantaneous die current supplied by these capacitors. Scope at socket. FAST: short local 0402 loops. Measure droop and overshoot at socket power/ground pads during kernel transitions.

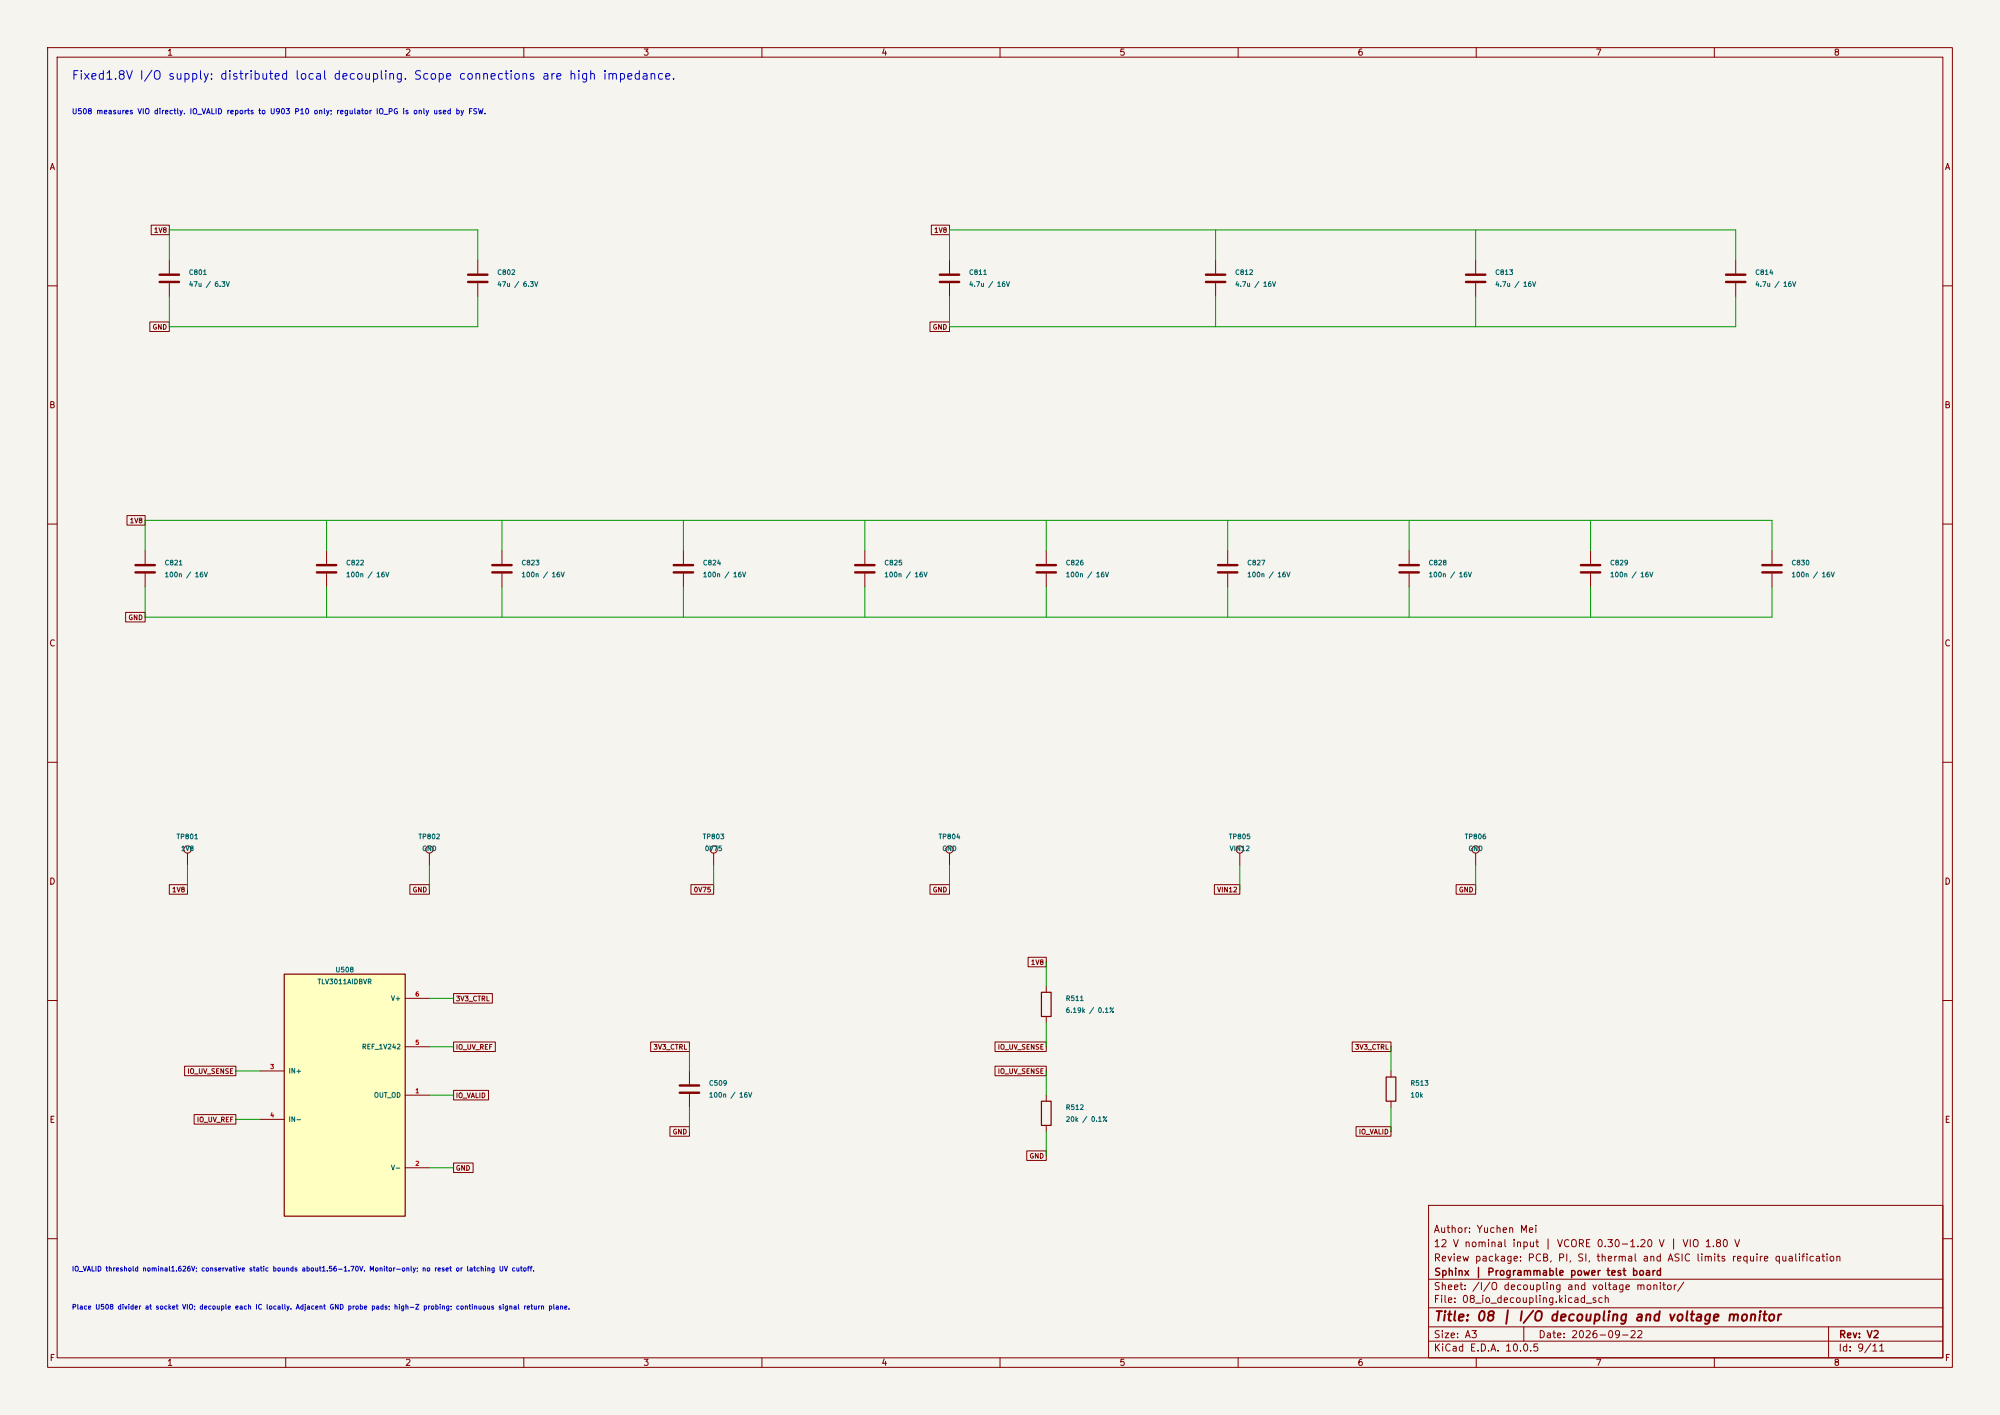
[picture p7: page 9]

Fixed1.8V I/O supply: distributed local decoupling. Scope connections are high impedance. U508 measures VIO directly. IO_VALID reports to U903 P10 only; regulator IO_PG is only used by FSW.

Author: Yuchen Mei
12 V nominal input | VCORE 0.30-1.20 V | VIO 1.80 V
Review package: PCB, PI, SI, thermal and ASIC limits require qualification
Sphinx | Programmable power test board
Sheet: /I/O decoupling and voltage monitor/
File: 08_io_decoupling.kicad_sch
Title: 08 | I/O decoupling and voltage monitor

IO_VALID threshold nominal1.626V; conservative static bounds about1.56-1.70V. Monitor-only; no reset or latching UV cutoff.

Place U508 divider at socket VIO; decouple each IC locally. Adjacent GND probe pads; high-Z probing; continuous signal return plane.

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
# Title: 09 | Independent control supply and retained board state

## File: 09_autonomous_control.kicad_sch

## Sheet: /09 | Independent control supply and retained board state/

## Sphinx | Programmable power test board
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

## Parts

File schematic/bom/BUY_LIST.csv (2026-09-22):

mpn | manufacturer | references | specification | quantity_per_board | fitted_per_board | dnp_references | purchase_quantity | optional_full_population_quantity | observed_stock | moq | lifecycle | source_url | china_order_url | checked_on | source_freshness | status | datasheet_url | source_access_method | spec_review_status | application_check
MFU1206FF03150P100 | Vishay | F101 | 3.15A, 63V, very-fast fuse, 1206; typical cold R37mOhm; P1=1000/reel packaging | 1 | 1 |  | 6 | 0 | 1000 | 1 | Active / listed for sale | https://www.digikey.com/en/products/detail/vishay/MFU1206FF03150P100/1206513 | https://www.digikey.cn/zh/products/detail/vishay/MFU1206FF03150P100/1206513 | 2026-09-17 | 4 months ago | PUBLIC_STOCK_SNAPSHOT | https://www.vishay.com/docs/28747/mfuserie.pdf | web_reader_page | NOMINAL_RATINGS_REVIEWED | Input backup fuse. Check inrush and temperature derating. A 3 A supply does not establish clearing of a 3.15 A fuse.
TPS259470LRPWR | Texas Instruments | U101 | 2.7-23V eFuse, latch-off L variant, adjustable current limit; RPW 10-pin 2x2mm | 1 | 1 |  | 6 | 0 | 543 | 1 | Active / listed for sale | https://www.digikey.com/en/products/detail/texas-instruments/TPS259470LRPWR/14124014 | https://www.digikey.cn/zh/products/detail/texas-instruments/TPS259470LRPWR/14124014 | 2026-09-17 | yesterday | PUBLIC_STOCK_SNAPSHOT | https://www.ti.com/lit/ds/symlink/tps25947.pdf | web_reader_page | NOMINAL_RATINGS_REVIEWED | R105 sets a nominal 2.69 A current limit. OVLO is approximately 14.4 V. U509 monitors post-eFuse VIN12 without clearing RUN_LATCH. Intrinsic UVLO/OVLO can recover if control power and the latch survive; FLT events still clear the latch. Connect ILM only to local R105; keep parasitic capacitance below 50 pF. Verify inrush and rapid interruption.
WSL2512R0100FEA | Vishay | R301 | 10mOhm +/-1%, 1W at70C, +/-75ppm/C, 2512; two terminals, PCB Kelvin sensing | 1 | 1 |  | 10 | 0 | 120777 | 1 | Active / listed for sale | https://www.digikey.com/en/products/detail/vishay-dale/WSL2512R0100FEA/712561 | https://www.digikey.cn/zh/products/detail/vishay-dale/WSL2512R0100FEA/712561 | 2026-09-17 | today | PUBLIC_STOCK_SNAPSHOT | https://www.vishay.com/docs/30100/wsl.pdf | web_reader_page | NOMINAL_RATINGS_REVIEWED | I/O current shunt; nominal dissipation is 10 mW at 1 A. Use independent Kelvin traces from the two-terminal pads and calibrate temperature dependence.
GRM32EC81E226KE15L | Murata | C104 C205 C206 C207 C208 | 22uF +/-10% 25V X6S 1210; DC-bias/effective capacitance to be qualified | 5 | 5 |  | 30 | 0 | 11490 | 1 | Active / listed for sale | https://www.digikey.com/en/products/detail/murata-electronics/GRM32EC81E226KE15L/2039089 | https://www.digikey.cn/zh/products/detail/murata-electronics/GRM32EC81E226KE15L/2039089 | 2026-09-17 | last week | PUBLIC_STOCK_SNAPSHOT | https://www.farnell.com/datasheets/2048738.pdf | search_index_snapshot | NOMINAL_RATINGS_REVIEWED | VIN12 decoupling. Evaluate effective capacitance at operating bias, ripple current, and input-network resonance.
TPS54302DDCR | Texas Instruments | U102 | 4.5-28V input, adjustable synchronous buck, 3A IC rating, 400kHz, DDC SOT23-6 | 1 | 1 |  | 6 | 0 | 13871 | 1 | Active / listed for sale | https://www.digikey.com/en/products/detail/texas-instruments/TPS54302DDCR/6572466 | https://www.digikey.cn/zh/products/detail/texas-instruments/TPS54302DDCR/6572466 | 2026-09-17 | yesterday | PUBLIC_STOCK_SNAPSHOT | https://www.ti.com/lit/ds/symlink/tps54302.pdf | web_reader_page | NOMINAL_RATINGS_REVIEWED | AUX regulator with a nominal 4.96 V output. EN is left floating as permitted by the datasheet. Verify the fitted input/output network on the board.
TPS546B24ARVFR | Texas Instruments | U201 | 2.95-18V input, 20A IC rating, PMBus; 0.25-3V across selected loop scales; RVF40 plus EP | 1 | 1 |  | 6 | 0 | 1394 | 1 | Active / listed for sale | https://www.digikey.com/en/products/detail/texas-instruments/TPS546B24ARVFR/13280055 | https://www.digikey.cn/zh/products/detail/texas-instruments/TPS546B24ARVFR/13280055 | 2026-09-17 | last week | PUBLIC_STOCK_SNAPSHOT | https://www.ti.com/lit/ds/symlink/tps546b24a.pdf | web_reader_page | NOMINAL_RATINGS_REVIEWED | Core regulator for the 0.30-1.20 V fixture range. The board continuous-current design target is 10 A. Program and read back compensation and protection for the fitted 12+12 or 16+16 capacitor population before enabling.
WSL25121L000FEA | Vishay | R201 | 1mOhm +/-1%, 1W at70C, +/-275ppm/C, 2512; two terminals, PCB Kelvin sensing | 1 | 1 |  | 10 | 0 | 9930 | 1 | Active / listed for sale | https://www.digikey.com/en/products/detail/vishay-dale/WSL25121L000FEA/712551 | https://www.digikey.cn/zh/products/detail/vishay-dale/WSL25121L000FEA/712551 | 2026-09-17 | last week | PUBLIC_STOCK_SNAPSHOT | https://www.vishay.com/docs/30100/wsl.pdf | web_reader_page | NOMINAL_RATINGS_REVIEWED | Core current shunt before the feedback endpoint. Nominal drop and dissipation at 10 A are 10 mV and 0.10 W. Calibrate resistance and temperature dependence.
TPS62131RGTR | Texas Instruments | U301 | FIXED1.8V synchronous buck, 3-17V input, 3A IC rating; RGT16 plus EP; NOT TPS62133 | 1 | 1 |  | 6 | 0 | 2077 | 1 | Active / listed for sale | https://www.digikey.com/en/products/detail/texas-instruments/TPS62131RGTR/2833430 | https://www.digikey.cn/zh/products/detail/texas-instruments/TPS62131RGTR/2833430 | 2026-09-17 | last week | PUBLIC_STOCK_SNAPSHOT | https://www.ti.com/lit/ds/symlink/tps62130.pdf | web_reader_page | NOMINAL_RATINGS_REVIEWED | Fixed 1.8 V I/O regulator with a 1 A provisioned load budget. Do not substitute the 5 V TPS62133. U508 generates IO_VALID. EN is supplied from local VIN12 through the Q301/Q302 interface; verify VIN-relative pin limits during startup and rapid power loss.
SRP5030T-2R2M | Bourns | L301 | 2.2uH +/-20%, DCR35mOhm max, Irms5.5A, Isat9A at20% L drop, 5x5x3mm | 1 | 1 |  | 6 | 0 | 7244 | 1 | Active / listed for sale | https://www.mouser.com/en/ProductDetail/Bourns/SRP5030T-2R2M?qs=Zq5ylnUbLm6RM9tJHvHtzA%3D%3D | https://www.mouser.cn/ProductDetail/Bourns/SRP5030T-2R2M?qs=Zq5ylnUbLm6RM9tJHvHtzA%3D%3D | 2026-09-17 | 6 days ago | PUBLIC_STOCK_SNAPSHOT | https://www.bourns.com/docs/Product-Datasheets/SRP5030T.pdf | web_reader_page | NOMINAL_RATINGS_REVIEWED | 2.2 uH I/O inductor. Verify ripple, peak current, inductance under bias, and temperature rise at the actual operating point.
SC0915 | Raspberry Pi | U401 | Original Raspberry Pi Pico RP2040, bare headers; VSYS1.8-5.5V, GPIO3.3V; 40-pin 2.54mm | 1 | 1 |  | 6 | 0 | 42985 | 1 | Active / listed for sale | https://www.digikey.com/en/products/detail/raspberry-pi/SC0915/13624793 | https://www.digikey.cn/zh/products/detail/raspberry-pi/SC0915/13624793 | 2026-09-17 | today | PUBLIC_STOCK_SNAPSHOT | https://datasheets.raspberrypi.com/pico/pico-datasheet.pdf | web_reader_page | NOMINAL_RATINGS_REVIEWED | Pico is a command-only USB interface. Only GP0/GP1 connect through ISO1640 side2; other GPIO/ADC pins are NC. Its3V3 only powers isolator side2 and local pullups. Board LDO U901 and U903 hold power/reset state; boot/rejoin/idle/USB errors must not mutate that state. Explicit commands only.
TL3342F160QG/TR | E-Switch | SW502 SW601 | Momentary NO SMT switch, 50mA at12VDC, 160gf, -20 to70C; tape/reel suffix /TR | 2 | 2 |  | 12 | 0 | 75264 | 1 | Active / listed for sale | https://www.digikey.com/en/products/detail/e-switch/TL3342F160QG-TR/379004 | https://www.digikey.cn/zh/products/detail/e-switch/TL3342F160QG-TR/379004 | 2026-09-17 | yesterday | PUBLIC_STOCK_SNAPSHOT | https://configured-product-images.s3.amazonaws.com/Datasheets/TL3342.pdf | web_reader_page | NOMINAL_RATINGS_REVIEWED | Momentary STOP and DUT RESET buttons. STOP clears the run latch; DUT RESET leaves the rails enabled. Keep local operating temperature within the 70 C switch rating.
TLV3011AIDBVR | Texas Instruments | U501 U508 U509 U1002 | 1.8-5.5V comparator, OPEN-DRAIN, 1.242V reference; DBV SOT23-6 | 4 | 4 |  | 24 | 0 | 4957 | 1 | Active / listed for sale | https://www.digikey.com/en/products/detail/texas-instruments/TLV3011AIDBVR/1678198 | https://www.digikey.cn/zh/products/detail/texas-instruments/TLV3011AIDBVR/1678198 | 2026-09-17 | 3 days ago | PUBLIC_STOCK_SNAPSHOT | https://www.ti.com/lit/ds/symlink/tlv3011.pdf | web_reader_page | NOMINAL_RATINGS_REVIEWED | U501 core OVP clears the power latch. U508 IO_VALID and U509 VIN12_VALID are independent telemetry only. Nominal thresholds are 1.319 V, 1.626 V, and 10.333 V. Evaluate tolerance, propagation delay, and temperature dependence.
TPS3808G33DBVR | Texas Instruments | U502 | 0.9-6.5V supervisor, G33 threshold3.07V, open-drain reset, CT100k pullup sets300ms nominal (180-420ms); DBV6 | 1 | 1 |  | 6 | 0 | 20208 | 1 | Active / listed for sale | https://www.digikey.com/en/products/detail/texas-instruments/TPS3808G33DBVR/666727 | https://www.digikey.cn/zh/products/detail/texas-instruments/TPS3808G33DBVR/666727 | 2026-09-17 | today | PUBLIC_STOCK_SNAPSHOT | https://www.ti.com/lit/ds/symlink/tps3808.pdf | web_reader_page | NOMINAL_RATINGS_REVIEWED | Independent3V3_CTRL supervisor clears RUN_LATCH on control brownout. CT pin4 connects through R1001=100k to3V3_CTRL for180ms minimum/300ms nominal/420ms maximum startup release delay, providing margin over TMP302 typical35ms startup; qualify hot-start corners.
SN74LVC1G74DCUR | Texas Instruments | U503 | 1.65-5.5V D flip-flop with asynchronous clear/preset; DCU VSSOP8 0.5mm pitch | 1 | 1 |  | 6 | 0 | 40331 | 1 | Active / listed for sale | https://www.digikey.com/en/products/detail/texas-instruments/SN74LVC1G74DCUR/2195376 | https://www.digikey.cn/zh/products/detail/texas-instruments/SN74LVC1G74DCUR/2195376 | 2026-09-17 | yesterday | PUBLIC_STOCK_SNAPSHOT | https://www.ti.com/lit/ds/symlink/sn74lvc1g74.pdf | web_reader_page | NOMINAL_RATINGS_REVIEWED | DCU pin 5 Q drives RUN_LATCH; pin 3 Q-bar is unconnected. CLR pin 6 and PRE pin 7 are active low; D and PRE are tied high. An explicit ON command or a commanded operating-range change generates one U903 P03 RUN_SET rising edge after startup checks. STOP and hardware faults clear the latch asynchronously; fault recovery alone must not issue another set pulse.
SN74LVC2G17DBVT | Texas Instruments | U507 | 1.65-5.5V dual Schmitt buffer; DBV SOT23-6; T reel packaging | 1 | 1 |  | 6 | 0 | 22492 | 1 | Active / listed for sale | https://www.digikey.com/en/products/detail/texas-instruments/SN74LVC2G17DBVT/1592283 | https://www.digikey.cn/zh/products/detail/texas-instruments/SN74LVC2G17DBVT/1592283 | 2026-09-17 | 2 days ago | PUBLIC_STOCK_SNAPSHOT | https://www.ti.com/lit/ds/symlink/sn74lvc2g17.pdf | web_reader_page | NOMINAL_RATINGS_REVIEWED | 3.3 V Schmitt buffering: channel 1 conditions U903 P03 RUN_SET into RUN_SET_CLEAN; channel 2 conditions open-drain HW_FAULT_N into HW_CLEAR_N. R507 keeps RUN_SET low while U903 P03 is high impedance.
74LVC08AT14-13 | Diodes Incorporated | U504 | 1.65-5.5V quad 2-input AND; TSSOP-14 4.4x5mm body, 0.65mm pitch; Ioff; -40..125C | 1 | 1 |  | 6 | 0 |  |  | Listed by manufacturer; inventory not checked | https://www.diodes.com/part/view/74LVC08A |  | 2026-09-19 | Manufacturer datasheet checked 2026-09-19; distributor inventory not checked | MANUFACTURER_SPEC_VERIFIED_STOCK_NOT_CHECKED | https://www.diodes.com/datasheet/download/74LVC08A.pdf | manufacturer_web_page_and_datasheet | PINMAP_DRIVE_AND_IOFF_REVIEWED_WITH_TRANSIENT_AND_TEMPERATURE_HOLDS | U504 gates only the two supply requests with RUN_LATCH. Pins 1/2/3 qualify CORE_REQ; 4/5/6 qualify IO_REQ. Unused inputs 9/10/12/13 are grounded, outputs 8/11 unconnected, pin 7 ground and 14 3V3_CTRL. Datasheet DS35261 Rev.4-2: at VCC=3V, VOH >=2.3V at -12mA through 85C (>=2.1V through 125C); at -24mA, >=2.2V/2.0V. R307=270 ohm can draw 13.5mA at 3.6V and -1% tolerance; the conservative 24mA level exceeds Q301's 1.8V gate-drive test point. Q301 full-temperature and transient performance still require board verification. At VCC=0, Ioff <=10uA through 85C or <=20uA through 125C with VI/VO up to 3.6V; existing output pull-downs remain required. Same pin numbers do not establish equivalent power-off behavior for another manufacturer.
280-5205-01 | 3M | J1 | 80-pin QFN 12x12mm 0.5mm pitch WITH thermal probe; 3M drawing 78-5100-2476-9 rev B; current/SI rating requires qualification | 1 | 1 |  | 6 | 0 | 21 | 1 | Active / listed for sale | https://www.digikey.hk/zh/products/detail/3m/280-5205-01/3133927 | https://www.digikey.cn/zh/products/detail/3m/280-5205-01/3133927 | 2026-09-17 | today | QUOTE_REQUIRED_STOCK_VARIANCE | https://multimedia.3m.com/mws/media/785852O/3m-tm-textool-tm-open-top-sockets-for-qfn-applications-cd2476.pdf | search_index_snapshot | HOLD_CURRENT_AND_2GHZ_QUALIFICATION | QFN80 socket for the specified pinout. Verify package fit, actuation clearance, support regions, and probe access against the manufacturer drawing.
132134 | Amphenol RF | J5 | Amphenol SMA straight PCB through-hole JACK, 50Ohm, manufacturer maximum18GHz; not -10/-11/-15 variants | 1 | 1 |  | 6 | 0 | 23952 | 1 | Active / listed for sale | https://www.digikey.com/en/products/detail/amphenol-rf/132134/1011907 | https://www.digikey.cn/zh/products/detail/amphenol-rf/132134/1011907 | 2026-09-17 | today | PUBLIC_STOCK_SNAPSHOT | https://www.amphenolrf.com/zh-cn/part/132134/662/ | web_reader_page | NOMINAL_RATINGS_REVIEWED | SMA clock input. Evaluate the connector transition, PCB trace, socket, and package as one signal path.
TCJD337M006R0012E | KYOCERA AVX | C701 C702 C703 C704 C705 C706 C707 C708 C761 C762 C763 C764 C765 C766 C767 C768 | 330uF +/-20%, 6.3V polymer tantalum, ESR12mOhm MAX at100kHz; D case; Tmax105C; Irms4.3/3.0/1.9A at45/85/105C; stripe=positive | 16 | 12 | C704 C708 C764 C768 | 72 | 24 | 500 | 1 | Active / listed for sale | https://www.mouser.com/en/ProductDetail/KYOCERA-AVX/TCJD337M006R0012E?qs=rkhjVJ6%2F3EIeaFnJOljhXA%3D%3D | https://www.mouser.cn/ProductDetail/KYOCERA-AVX/TCJD337M006R0012E?qs=rkhjVJ6%2F3EIeaFnJOljhXA%3D%3D | 2026-09-17 | 3 weeks ago | PUBLIC_STOCK_SNAPSHOT | https://datasheets.kyocera-avx.com/TCJ.pdf | search_index_snapshot | NOMINAL_RATINGS_REVIEWED | Fit 12 of 16 polymer positions by default. C704/C708/C764/C768 are DNP. Match controller compensation to the fitted population. The stripe marks the positive terminal.
SRP7028A-100M | Bourns | L101 | 10uH +/-20%; DCR85mOhm max; Irms3.5A; Isat6A (20% drop); 7.3x6.6x3.0mm | 1 | 1 |  | 6 | 0 | 6604 | 1 | Active / listed for sale | https://www.digikey.com/en/products/detail/bourns-inc/SRP7028A-100M/4876641 | https://www.digikey.cn/zh/products/detail/bourns-inc/SRP7028A-100M/4876641 | 2026-09-17 | last week | PUBLIC_STOCK_SNAPSHOT | https://www.bourns.com/docs/Product-Datasheets/SRP7028A.pdf | web_reader_page | NOMINAL_RATINGS_REVIEWED | AUX output inductor. Verify ripple, peak current, and temperature rise with the actual controller and accessory load.
XAL1030-561MEC | Coilcraft | L201 | 0.56uH +/-20%; DCR2.75mOhm max; Isat44A (30% drop); Irms23A/32A (20C/40C rise); 11.3x10x3.1mm | 1 | 1 |  | 6 | 0 | 180 | 1 | Active / listed for sale | https://www.mouser.com/ProductDetail/Coilcraft/XAL1030-561MEC?qs=zCSbvcPd3pYdubMuVAT72A%3D%3D | https://www.mouser.cn/ProductDetail/Coilcraft/XAL1030-561MEC?qs=zCSbvcPd3pYdubMuVAT72A%3D%3D | 2026-09-17 | 2 months ago | PUBLIC_STOCK_SNAPSHOT | https://www.coilcraft.com/getmedia/7b108457-7731-456d-9256-ca72f2e1a551/xal1030.pdf | search_index_snapshot | NOMINAL_RATINGS_REVIEWED | 0.56 uH core inductor. At 10 A, DC copper loss calculated from the 2.75 milliohm maximum DCR is 0.275 W. Measure total loss, temperature, and inductance under bias.
INA226AIDGSR | Texas Instruments | U302 U303 | 2.7-5.5V supply, 0-36V common-mode, +/-81.92mV shunt ADC, DGS10; INA226 register map | 2 | 2 |  | 12 | 0 | 92158 | 1 | Active / listed for sale | https://www.digikey.cn/zh/products/detail/texas-instruments/INA226AIDGSR/2687236 | https://www.digikey.cn/zh/products/detail/texas-instruments/INA226AIDGSR/2687236 | 2026-09-17 | last week | PUBLIC_STOCK_SNAPSHOT | https://www.ti.com/lit/ds/symlink/ina226.pdf | web_reader_page | NOMINAL_RATINGS_REVIEWED | Core and I/O telemetry. Configuration 0x4297 gives a nominal 2.656 ms averaged update period. Use an oscilloscope for individual kernel transients.
CL32A107MQVNNWE | Samsung Electro-Mechanics | C711 C712 C713 C714 C715 C716 C717 C718 C771 C772 C773 C774 C775 C776 C777 C778 | 100uF +/-20% 6.3V X5R 1210; max thickness2.8mm; bias/thermal effective capacitance needs qualification | 16 | 12 | C714 C718 C774 C778 | 72 | 24 | 9651 | 1 | Active / listed for sale | https://www.digikey.com/en/products/detail/samsung-electro-mechanics/CL32A107MQVNNWE/3889024 | https://www.digikey.cn/zh/products/detail/samsung-electro-mechanics/CL32A107MQVNNWE/3889024 | 2026-09-17 | last week | PUBLIC_STOCK_SNAPSHOT | https://product.samsungsem.com/mlcc/CL32A107MQVNNW.do | web_reader_page | NOMINAL_RATINGS_REVIEWED | Fit 12 of 16 large-MLCC positions by default. C714/C718/C774/C778 are DNP. Determine effective capacitance at the actual voltage and temperature.
SS14-E3/61T | Vishay | D401 | 1A 40V Schottky SMA; pad1=cathode VSYS; pad2=anode AUX5V | 1 | 1 |  | 6 | 0 | 98297 | 1 | Active / listed for sale | https://www.digikey.in/en/products/detail/vishay-general-semiconductor-diodes-division/SS14-E3-61T/1091538 | https://www.digikey.cn/zh/products/detail/vishay-general-semiconductor-diodes-division/SS14-E3-61T/1091538 | 2026-09-17 | last week | PUBLIC_STOCK_SNAPSHOT | https://www.vishay.com/docs/88746/ss12.pdf | web_reader_page | NOMINAL_RATINGS_REVIEWED | AUX5V-to-Pico VSYS diode. Cathode pad 1 connects to VSYS. Check forward drop and temperature at the actual controller load.
MMBT3904-7-F | Diodes Incorporated | Q601 | NPN SOT23; pin1=B, pin2=E, pin3=C | 1 | 1 |  | 6 | 0 | 755229 | 1 | Active / listed for sale | https://www.digikey.com/en/products/detail/diodes-incorporated/MMBT3904-7-F/814494 | https://www.digikey.cn/zh/products/detail/diodes-incorporated/MMBT3904-7-F/814494 | 2026-09-17 | today | PUBLIC_STOCK_SNAPSHOT | https://www.diodes.com/assets/Datasheets/MMBT3904.pdf | web_reader_page | NOMINAL_RATINGS_REVIEWED | DUT reset pull-down transistor; B/E/C are pins 1/2/3. R603 biases its base from VIO so valid VIO defaults to released reset. SW601, U601 or Q602 sinks RESET_BASE to assert reset through R602. Nominal collector load is 0.18 mA; nominal net base current is about 44 uA at VIO=1.8 V and VBE=0.7 V. Verify reset levels and edges on the assembled board.
RC0603FR-0778K7L | YAGEO | R101 | 78.7k +/-1% 0.1W 0603 thick film; +/-100ppm/C | 1 | 1 |  | 10 | 0 | 73531 | 1 | Active / listed for sale | https://www.digikey.com/en/products/detail/yageo/RC0603FR-0778K7L/727386 | https://www.digikey.cn/zh/products/detail/yageo/RC0603FR-0778K7L/727386 | 2026-09-17 | 4 weeks ago | PUBLIC_STOCK_SNAPSHOT | https://yageogroup.com/component-documentation/download/specsheet/RC0603FR-0778K7L | web_reader_page | NOMINAL_RATINGS_REVIEWED | Input UVLO upper divider resistor. Include its 1% tolerance in threshold evaluation.
RC0603FR-0710KL | YAGEO | R102 R104 R108 R207 R211 R302 R306 R403 R404 R506 R507 R513 R515 R516 R602 R1004 R1005 R1006 R1007 R1008 R1009 | 10k +/-1% 0.1W 0603 thick film; +/-100ppm/C | 21 | 21 |  | 126 | 0 | 1706112 | 1 | Active / listed for sale | https://www.digikey.com/en/products/detail/yageo/RC0603FR-0710KL/726880 | https://www.digikey.cn/zh/products/detail/yageo/RC0603FR-0710KL/726880 | 2026-09-17 | today | PUBLIC_STOCK_SNAPSHOT | https://yageogroup.com/component-documentation/download/specsheet/RC0603FR-0710KL | web_reader_page | NOMINAL_RATINGS_REVIEWED | Pull-ups, divider resistors, and logic bias. R306 biases IO_EN_INHIBIT from VIN12. R507 holds RUN_SET low while U903 P03 is high impedance. Check dissipation at maximum input voltage. R516 pulls the independent VIN12_VALID monitor output high; it is not on the fault bus.
RC0603FR-07110KL | YAGEO | R103 | 110k +/-1% 0.1W 0603 thick film; +/-100ppm/C | 1 | 1 |  | 10 | 0 | 203528 | 1 | Active / listed for sale | https://www.digikey.com/en/products/detail/yageo/RC0603FR-07110KL/726905 | https://www.digikey.cn/zh/products/detail/yageo/RC0603FR-07110KL/726905 | 2026-09-17 | 2 days ago | PUBLIC_STOCK_SNAPSHOT | https://yageogroup.com/component-documentation/download/specsheet/RC0603FR-07110KL | web_reader_page | NOMINAL_RATINGS_REVIEWED | Input OVLO upper divider resistor. Evaluate the resulting threshold with device and resistor tolerances.
RC0603FR-071K24L | YAGEO | R105 R503 | 1.24k +/-1% 0.1W 0603 thick film; +/-100ppm/C | 2 | 2 |  | 12 | 0 | 40979 | 1 | Active / listed for sale | https://www.digikey.com/en/products/detail/yageo/RC0603FR-071K24L/726856 | https://www.digikey.cn/zh/products/detail/yageo/RC0603FR-071K24L/726856 | 2026-09-17 | 5 months ago | PUBLIC_STOCK_SNAPSHOT | https://yageogroup.com/component-documentation/download/specsheet/RC0603FR-071K24L | web_reader_page | NOMINAL_RATINGS_REVIEWED | R105 sets eFuse current limit. R503 forms the core OVP divider with R504. Route OVP sense independently from the socket supply plane.
RC0603FR-0773K2L | YAGEO | R107 R514 | 73.2k +/-1% 0.1W 0603 thick film; +/-100ppm/C | 2 | 2 |  | 12 | 0 | 11442 | 1 | Active / listed for sale | https://www.digikey.com/en/products/detail/yageo/RC0603FR-0773K2L/727374 | https://www.digikey.cn/zh/products/detail/yageo/RC0603FR-0773K2L/727374 | 2026-09-17 | 2 weeks ago | PUBLIC_STOCK_SNAPSHOT | https://yageogroup.com/component-documentation/download/specsheet/RC0603FR-0773K2L | web_reader_page | NOMINAL_RATINGS_REVIEWED | R107 sets AUX output voltage. R514 forms the post-eFuse input detector divider with R515; nominal threshold 10.333 V.
RC0603FR-0710RL | YAGEO | R202 R310 R311 R320 R321 | 10R +/-1% 0.1W 0603 thick film; +/-200ppm/C | 5 | 5 |  | 30 | 0 | 17164 | 1 | Active / listed for sale | https://www.digikey.com/en/products/detail/yageo/RC0603FR-0710RL/726879 | https://www.digikey.cn/zh/products/detail/yageo/RC0603FR-0710RL/726879 | 2026-09-17 | today | PUBLIC_STOCK_SNAPSHOT | https://yageogroup.com/component-documentation/download/specsheet/RC0603FR-0710RL | web_reader_page | NOMINAL_RATINGS_REVIEWED | Core AVIN damping and core/I/O INA226 differential input filters. Place monitor filter components close to their ICs.
AC0603FR-0712K1L | YAGEO | R204 R208 | 12.1kOhm +/-1%, 0.1W at70C, +/-100ppm/C, 0603; automotive AC series, same strap value | 2 | 2 |  | 12 | 0 | 97632 | 1 | Active / listed for sale | https://www.digikey.com/en/products/detail/yageo/AC0603FR-0712K1L/5895768 | https://www.digikey.cn/zh/products/detail/yageo/AC0603FR-0712K1L/5895768 | 2026-09-17 | 4 days ago | PUBLIC_STOCK_SNAPSHOT | https://yageogroup.com/component-documentation/download/specsheet/AC0603FR-0712K1L | search_index_snapshot | NOMINAL_RATINGS_REVIEWED | R204/MSEL1 and R208/VSEL strap resistors. Preserve the specified resistance, tolerance, and package.
RC0603FR-0721K5L | YAGEO | R205 R603 | 21.5k +/-1% 0.1W 0603 thick film; +/-100ppm/C | 2 | 2 |  | 12 | 0 | 766092 | 1 | Active / listed for sale | https://www.digikey.com/en/products/detail/yageo/RC0603FR-0721K5L/729997 | https://www.digikey.cn/zh/products/detail/yageo/RC0603FR-0721K5L/729997 | 2026-09-17 | 3 months ago | PUBLIC_STOCK_SNAPSHOT | https://yageogroup.com/component-documentation/download/specsheet/RC0603FR-0721K5L | web_reader_page | NOMINAL_RATINGS_REVIEWED | R205 sets the MSEL1 startup strap. R603 biases Q601 from VIO for default reset release and limits the explicit reset sink current. Verify DUT reset high/low levels and remote-reset timing.
RC0603FR-0719K6L | YAGEO | R206 | 19.6k +/-1% 0.1W 0603 thick film; +/-100ppm/C | 1 | 1 |  | 10 | 0 | 20375 | 1 | Active / listed for sale | https://www.digikey.com/en/products/detail/yageo/RC0603FR-0719K6L/727003 | https://www.digikey.cn/zh/products/detail/yageo/RC0603FR-0719K6L/727003 | 2026-09-17 | today | PUBLIC_STOCK_SNAPSHOT | https://yageogroup.com/component-documentation/download/specsheet/RC0603FR-0719K6L | web_reader_page | NOMINAL_RATINGS_REVIEWED | MSEL2 upper strap resistor for the configured startup behavior. Preserve its 1% tolerance.
RC0603FR-074K64L | YAGEO | R209 | 4.64k +/-1% 0.1W 0603 thick film; +/-100ppm/C | 1 | 1 |  | 10 | 0 | 73230 | 1 | Active / listed for sale | https://www.digikey.com/en/products/detail/yageo/RC0603FR-074K64L/727211 | https://www.digikey.cn/zh/products/detail/yageo/RC0603FR-074K64L/727211 | 2026-09-17 | last week | PUBLIC_STOCK_SNAPSHOT | https://yageogroup.com/component-documentation/download/specsheet/RC0603FR-074K64L | web_reader_page | NOMINAL_RATINGS_REVIEWED | R209 connects ADRSEL to ground with no upper resistor. The 4.64 kohm value selects 7-bit PMBus address 0x10 and automatic SYNC detection.
RC0603FR-07100KL | YAGEO | R210 R408 R411 R509 R510 R604 R903 R1001 | 100k +/-1% 0.1W 0603 thick film; +/-100ppm/C | 8 | 8 |  | 48 | 0 | 1291514 | 1 | Active / listed for sale | https://www.digikey.com/en/products/detail/yageo/RC0603FR-07100KL/726889 | https://www.digikey.cn/zh/products/detail/yageo/RC0603FR-07100KL/726889 | 2026-09-17 | today | PUBLIC_STOCK_SNAPSHOT | https://yageogroup.com/component-documentation/download/specsheet/RC0603FR-07100KL | web_reader_page | NOMINAL_RATINGS_REVIEWED | Control pull-downs and NTC divider. Use the specified resistance and tolerance. R411 holds RESET_ASSERT low when U903 P02 is high impedance; place it beside Q602.
RC0603FR-072K2L | YAGEO | R401 R402 R901 R902 | 2.2k +/-1% 0.1W 0603 thick film; +/-100ppm/C | 4 | 4 |  | 24 | 0 | 498300 | 1 | Active / listed for sale | https://www.digikey.in/en/products/detail/yageo/RC0603FR-072K2L/727016 | https://www.digikey.cn/zh/products/detail/yageo/RC0603FR-072K2L/727016 | 2026-09-17 | last week | PUBLIC_STOCK_SNAPSHOT | https://yageogroup.com/component-documentation/download/specsheet/RC0603FR-072K2L | web_reader_page | NOMINAL_RATINGS_REVIEWED | 3.3 V I2C pull-ups. Nominal low-state current is 1.5 mA per line. Measure rise time with the installed bus capacitance.
RC0603FR-0749R9L | YAGEO | R601 | 49.9R +/-1% 0.1W 0603 thick film; +/-100ppm/C | 1 | 0 | R601 | 0 | 6 | 471025 | 1 | Active / listed for sale | https://www.digikey.com/en/products/detail/yageo/RC0603FR-0749R9L/727264 | https://www.digikey.cn/zh/products/detail/yageo/RC0603FR-0749R9L/727264 | 2026-09-17 | yesterday | PUBLIC_STOCK_SNAPSHOT | https://yageogroup.com/component-documentation/download/specsheet/RC0603FR-0749R9L | web_reader_page | NOMINAL_RATINGS_REVIEWED | R601 clock termination; DNP by default. Confirm source configuration, receiver amplitude, and driver loading before fitting.
RT0603BRD076K19L | YAGEO | R511 | 6.19kOhm +/-0.1% 0.1W 0603 thin film; 25ppm/C | 1 | 1 |  | 10 | 0 | 10000 | 1 | Active / listed for sale | https://www.digikey.com/en/products/detail/yageo/RT0603BRD076K19L/1072628 | https://www.digikey.cn/zh/products/detail/yageo/RT0603BRD076K19L/1072628 | 2026-09-17 | last month | PUBLIC_STOCK_SNAPSHOT | https://yageogroup.com/component-documentation/download/specsheet/RT0603BRD076K19L | web_reader_page | NOMINAL_RATINGS_REVIEWED | R511 forms the I/O-valid divider with R512; nominal threshold 1.626 V.
RT0603BRD0720KL | YAGEO | R504 R512 R1003 | 20kOhm +/-0.1% 0.1W 0603 thin film; 25ppm/C | 3 | 3 |  | 18 | 0 | 86457 | 1 | Active / listed for sale | https://www.digikey.com/en/products/detail/yageo/RT0603BRD0720KL/5139030 | https://www.digikey.cn/zh/products/detail/yageo/RT0603BRD0720KL/5139030 | 2026-09-17 | 4 days ago | PUBLIC_STOCK_SNAPSHOT | https://yageogroup.com/component-documentation/download/specsheet/RT0603BRD0720KL | web_reader_page | NOMINAL_RATINGS_REVIEWED | R504 is the core OVP lower resistor; R512 is the I/O-valid lower resistor. Include reference, offset, and resistor tolerances in threshold evaluation.
RC1206FR-071RL | YAGEO | R203 | 1Ohm +/-1% 0.25W 1206; snubber tuning required; +/-200ppm/C; rated at70C | 1 | 1 |  | 10 | 0 | 223509 | 1 | Active / listed for sale | https://www.digikey.com/en/products/detail/yageo/RC1206FR-071RL/728386 | https://www.digikey.cn/zh/products/detail/yageo/RC1206FR-071RL/728386 | 2026-09-17 | 2 days ago | PUBLIC_STOCK_SNAPSHOT | https://yageogroup.com/component-documentation/download/specsheet/RC1206FR-071RL | web_reader_page | NOMINAL_RATINGS_REVIEWED | Switch-node snubber resistor. Determine pulse dissipation, temperature, and damping from measured ringing.
ERJ-P06F47R0V | Panasonic | R212 | 47Ohm +/-1%, 0.5W, +/-100ppm/C, 0805; core bleed30.6mW at1.2V; thermal derating applies | 1 | 1 |  | 10 | 0 | 30000 | 1 | Active / listed for sale | https://www.digikey.com/en/products/detail/panasonic-industry/ERJ-P06F47R0V/21281855 | https://www.digikey.cn/zh/products/detail/panasonic-industry/ERJ-P06F47R0V/21281855 | 2026-09-17 | 2 months ago | PUBLIC_STOCK_SNAPSHOT | https://industrial.panasonic.com/cdbs/www-data/pdf/RDO0000/AOA0000C331.pdf | web_reader_page | NOMINAL_RATINGS_REVIEWED | R212 core discharge resistor. Nominal dissipation is 30.6 mW at 1.2 V. Confirm measured discharge below 50 mV before changing feedback scale.
ERJ-P06F1000V | Panasonic | R304 R308 | 100Ohm +/-1%, 0.5W, +/-100ppm/C, 0805; IO bleed32.4mW at1.8V; thermal derating applies | 2 | 2 |  | 12 | 0 | 208504 | 1 | Active / listed for sale | https://www.digikey.com/en/products/detail/panasonic-industry/ERJ-P06F1000V/3982698 | https://www.digikey.cn/zh/products/detail/panasonic-industry/ERJ-P06F1000V/3982698 | 2026-09-17 | 2 days ago | PUBLIC_STOCK_SNAPSHOT | https://industrial.panasonic.com/cdbs/www-data/pdf/RDO0000/AOA0000C331.pdf | web_reader_page | NOMINAL_RATINGS_REVIEWED | R304 discharges I/O. R308 limits Q302 gate discharge and coupling into IO_EN. Preserve the 100 ohm, 0.5 W, 0805 specification and verify pulse stress.
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

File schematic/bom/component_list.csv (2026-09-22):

Reference | Value | MPN | Footprint | DNP | Description | Datasheet
C101 | 1u / 50V | C0805C105K5RACTU | Sphinx_V2:Capacitor_SMD__C_0805_2012Metric | no | 1uF +/-10% 50V X7R 0805 | https://content.kemet.com/datasheets/KEM_C1002_X7R_SMD.pdf
C102 | 100n / 100V | GRM188R72A104KA35D | Sphinx_V2:Capacitor_SMD__C_0603_1608Metric | no | 100nF +/-10% 100V X7R 0603 | https://search.murata.co.jp/Ceramy/image/img/A01X/G101/ENG/GRM188R72A104KA35-01A.pdf
C103 | 10n / 50V | CL10B103KB8NNNC | Sphinx_V2:Capacitor_SMD__C_0603_1608Metric | no | 10nF +/-10% 50V X7R 0603 | https://product.samsungsem.com/mlcc/CL10B103KB8NNN.do
C104 | 22u / 25V | GRM32EC81E226KE15L | Sphinx_V2:Capacitor_SMD__C_1210_3225Metric | no | Local input ceramic; C205-C208 provide another88u nominal; qualify cable input resonance | 22uF +/-10% 25V X6S 1210; DC-bias/effective capacitance to be qualified | https://www.farnell.com/datasheets/2048738.pdf
C105 | 1u / 50V | C0805C105K5RACTU | Sphinx_V2:Capacitor_SMD__C_0805_2012Metric | no | 1uF +/-10% 50V X7R 0805 | https://content.kemet.com/datasheets/KEM_C1002_X7R_SMD.pdf
C106 | 10u / 35V X7R | CL31B106KLHNFNE | Sphinx_V2:Capacitor_SMD__C_1206_3216Metric | no | 10uF +/-10%, 35V, X7R, 1206, thickness1.6+/-0.2mm; AUX/IO INPUT bypass | https://product.samsungsem.com/mlcc/CL31B106KLHNFN.do
C107 | 100n / 100V | GRM188R72A104KA35D | Sphinx_V2:Capacitor_SMD__C_0603_1608Metric | no | 100nF +/-10% 100V X7R 0603 | https://search.murata.co.jp/Ceramy/image/img/A01X/G101/ENG/GRM188R72A104KA35-01A.pdf
C108 | 22u / 10V | CL21A226MPQNNNE | Sphinx_V2:Capacitor_SMD__C_0805_2012Metric | no | 22uF +/-20% 10V X5R 0805 | https://product.samsungsem.com/mlcc/CL21A226MPQNNN.do
C109 | 22u / 10V | CL21A226MPQNNNE | Sphinx_V2:Capacitor_SMD__C_0805_2012Metric | no | 22uF +/-20% 10V X5R 0805 | https://product.samsungsem.com/mlcc/CL21A226MPQNNN.do
C201 | 100n / 100V | GRM188R72A104KA35D | Sphinx_V2:Capacitor_SMD__C_0603_1608Metric | no | 100nF +/-10% 100V X7R 0603 | https://search.murata.co.jp/Ceramy/image/img/A01X/G101/ENG/GRM188R72A104KA35-01A.pdf
C202 | 4.7u / 16V | CL21B475KOFNNNE | Sphinx_V2:Capacitor_SMD__C_0805_2012Metric | no | 4.7uF +/-10% 16V X7R 0805 | https://product.samsungsem.com/mlcc/CL21B475KOFNNN.do
C203 | 1u / 10V | CL10B105KP8NNNC | Sphinx_V2:Capacitor_SMD__C_0603_1608Metric | no | 1uF +/-10% 10V X7R 0603 | https://product.samsungsem.com/mlcc/CL10B105KP8NNN.do
C204 | 1u / 50V | C0805C105K5RACTU | Sphinx_V2:Capacitor_SMD__C_0805_2012Metric | no | 1uF +/-10% 50V X7R 0805 | https://content.kemet.com/datasheets/KEM_C1002_X7R_SMD.pdf
C205 | 22u / 25V | GRM32EC81E226KE15L | Sphinx_V2:Capacitor_SMD__C_1210_3225Metric | no | 22uF +/-10% 25V X6S 1210; DC-bias/effective capacitance to be qualified | https://www.farnell.com/datasheets/2048738.pdf
C206 | 22u / 25V | GRM32EC81E226KE15L | Sphinx_V2:Capacitor_SMD__C_1210_3225Metric | no | 22uF +/-10% 25V X6S 1210; DC-bias/effective capacitance to be qualified | https://www.farnell.com/datasheets/2048738.pdf
C207 | 22u / 25V | GRM32EC81E226KE15L | Sphinx_V2:Capacitor_SMD__C_1210_3225Metric | no | 22uF +/-10% 25V X6S 1210; DC-bias/effective capacitance to be qualified | https://www.farnell.com/datasheets/2048738.pdf
C208 | 22u / 25V | GRM32EC81E226KE15L | Sphinx_V2:Capacitor_SMD__C_1210_3225Metric | no | 22uF +/-10% 25V X6S 1210; DC-bias/effective capacitance to be qualified | https://www.farnell.com/datasheets/2048738.pdf
C209 | 4.7n / 25V | GRM155R71E472KA01D | Sphinx_V2:Capacitor_SMD__C_0402_1005Metric | no | Place immediately at PVIN/PGND pins | 4.7nF +/-10% 25V X7R 0402 | https://search.murata.co.jp/Ceramy/image/img/A01X/G101/ENG/GRM155R71E472KA01-01A.pdf
C210 | 1n / 50V | GRM1885C1H102JA01D | Sphinx_V2:Capacitor_SMD__C_0603_1608Metric | no | 1nF +/-5% 50V C0G 0603 | https://search.murata.co.jp/Ceramy/image/img/A01X/G101/ENG/GRM1885C1H102JA01-01A.pdf
C301 | 10u / 35V X7R | CL31B106KLHNFNE | Sphinx_V2:Capacitor_SMD__C_1206_3216Metric | no | 10uF +/-10%, 35V, X7R, 1206, thickness1.6+/-0.2mm; AUX/IO INPUT bypass | https://product.samsungsem.com/mlcc/CL31B106KLHNFN.do
C302 | 100n / 100V | GRM188R72A104KA35D | Sphinx_V2:Capacitor_SMD__C_0603_1608Metric | no | 100nF +/-10% 100V X7R 0603 | https://search.murata.co.jp/Ceramy/image/img/A01X/G101/ENG/GRM188R72A104KA35-01A.pdf
C303 | 10n / 50V | CL10B103KB8NNNC | Sphinx_V2:Capacitor_SMD__C_0603_1608Metric | no | 10nF +/-10% 50V X7R 0603 | https://product.samsungsem.com/mlcc/CL10B103KB8NNN.do
C304 | 22u / 10V | CL21A226MPQNNNE | Sphinx_V2:Capacitor_SMD__C_0805_2012Metric | no | 22uF +/-20% 10V X5R 0805 | https://product.samsungsem.com/mlcc/CL21A226MPQNNN.do
C305 | 22u / 10V | CL21A226MPQNNNE | Sphinx_V2:Capacitor_SMD__C_0805_2012Metric | no | 22uF +/-20% 10V X5R 0805 | https://product.samsungsem.com/mlcc/CL21A226MPQNNN.do
C306 | 1n / 50V | GRM1885C1H102JA01D | Sphinx_V2:Capacitor_SMD__C_0603_1608Metric | no | C0G 1nF +/-5% VIN-to-inhibit feedforward; mandatory for fast default-off startup. | 1nF +/-5% 50V C0G 0603 | https://search.murata.co.jp/Ceramy/image/img/A01X/G101/ENG/GRM1885C1H102JA01-01A.pdf
C307 | 100p / 100V | GRM1885C2A101JA01D | Sphinx_V2:Capacitor_SMD__C_0603_1608Metric | no | C0G 100pF +/-5%; limits Miller transient. Do not omit or enlarge without requalification. | 100pF +/-5% 100V C0G 0603; -55..125C operating range | https://search.murata.co.jp/Ceramy/image/img/A01X/G101/ENG/GRM1885C2A101JA01-01A.pdf
C310 | 100n / 100V | GRM188R72A104KA35D | Sphinx_V2:Capacitor_SMD__C_0603_1608Metric | no | 100nF +/-10% 100V X7R 0603 | https://search.murata.co.jp/Ceramy/image/img/A01X/G101/ENG/GRM188R72A104KA35-01A.pdf
C311 | 10n / 50V | CL10B103KB8NNNC | Sphinx_V2:Capacitor_SMD__C_0603_1608Metric | no | 10nF +/-10% 50V X7R 0603 | https://product.samsungsem.com/mlcc/CL10B103KB8NNN.do
C320 | 100n / 100V | GRM188R72A104KA35D | Sphinx_V2:Capacitor_SMD__C_0603_1608Metric | no | 100nF +/-10% 100V X7R 0603 | https://search.murata.co.jp/Ceramy/image/img/A01X/G101/ENG/GRM188R72A104KA35-01A.pdf
C321 | 10n / 50V | CL10B103KB8NNNC | Sphinx_V2:Capacitor_SMD__C_0603_1608Metric | no | 10nF +/-10% 50V X7R 0603 | https://product.samsungsem.com/mlcc/CL10B103KB8NNN.do
C401 | 22u / 10V | CL21A226MPQNNNE | Sphinx_V2:Capacitor_SMD__C_0805_2012Metric | no | 22uF +/-20% 10V X5R 0805 | https://product.samsungsem.com/mlcc/CL21A226MPQNNN.do
C502 | 100n / 16V | CL05B104KO5NNNC | Sphinx_V2:Capacitor_SMD__C_0402_1005Metric | no | 100nF +/-10% 16V X7R 0402 | https://product.samsungsem.com/mlcc/CL05B104KO5NNN.do
C503 | 100n / 16V | CL05B104KO5NNNC | Sphinx_V2:Capacitor_SMD__C_0402_1005Metric | no | 100nF +/-10% 16V X7R 0402 | https://product.samsungsem.com/mlcc/CL05B104KO5NNN.do
C504 | 100n / 16V | CL05B104KO5NNNC | Sphinx_V2:Capacitor_SMD__C_0402_1005Metric | no | 100nF +/-10% 16V X7R 0402 | https://product.samsungsem.com/mlcc/CL05B104KO5NNN.do
C506 | 100n / 16V | CL05B104KO5NNNC | Sphinx_V2:Capacitor_SMD__C_0402_1005Metric | no | 100nF +/-10% 16V X7R 0402 | https://product.samsungsem.com/mlcc/CL05B104KO5NNN.do
C508 | 100n / 16V | CL05B104KO5NNNC | Sphinx_V2:Capacitor_SMD__C_0402_1005Metric | no | 100nF +/-10% 16V X7R 0402 | https://product.samsungsem.com/mlcc/CL05B104KO5NNN.do
C509 | 100n / 16V | CL05B104KO5NNNC | Sphinx_V2:Capacitor_SMD__C_0402_1005Metric | no | 100nF +/-10% 16V X7R 0402 | https://product.samsungsem.com/mlcc/CL05B104KO5NNN.do
C510 | 100n / 16V | CL05B104KO5NNNC | Sphinx_V2:Capacitor_SMD__C_0402_1005Metric | no | 100nF +/-10% 16V X7R 0402 | https://product.samsungsem.com/mlcc/CL05B104KO5NNN.do
C701 | 330u / 6.3V | TCJD337M006R0012E | Sphinx_V2:Capacitor_Tantalum_SMD__CP_EIA-7343-31_Kemet-D | no | Polymer tantalum; ESR12mOhm max; D case; positive stripe to core; local transient storage | 330uF +/-20%, 6.3V polymer tantalum, ESR12mOhm MAX at100kHz; D case; Tmax105C; Irms4.3/3.0/1.9A at45/85/105C; stripe=positive | https://datasheets.kyocera-avx.com/TCJ.pdf
C702 | 330u / 6.3V | TCJD337M006R0012E | Sphinx_V2:Capacitor_Tantalum_SMD__CP_EIA-7343-31_Kemet-D | no | Polymer tantalum; ESR12mOhm max; D case; positive stripe to core; local transient storage | 330uF +/-20%, 6.3V polymer tantalum, ESR12mOhm MAX at100kHz; D case; Tmax105C; Irms4.3/3.0/1.9A at45/85/105C; stripe=positive | https://datasheets.kyocera-avx.com/TCJ.pdf
C703 | 330u / 6.3V | TCJD337M006R0012E | Sphinx_V2:Capacitor_Tantalum_SMD__CP_EIA-7343-31_Kemet-D | no | Polymer tantalum; ESR12mOhm max; D case; positive stripe to core; local transient storage | 330uF +/-20%, 6.3V polymer tantalum, ESR12mOhm MAX at100kHz; D case; Tmax105C; Irms4.3/3.0/1.9A at45/85/105C; stripe=positive | https://datasheets.kyocera-avx.com/TCJ.pdf
C704 | 330u / 6.3V | TCJD337M006R0012E | Sphinx_V2:Capacitor_Tantalum_SMD__CP_EIA-7343-31_Kemet-D | yes | Polymer tantalum; ESR12mOhm max; D case; positive stripe to core; local transient storage | 330uF +/-20%, 6.3V polymer tantalum, ESR12mOhm MAX at100kHz; D case; Tmax105C; Irms4.3/3.0/1.9A at45/85/105C; stripe=positive | https://datasheets.kyocera-avx.com/TCJ.pdf
C705 | 330u / 6.3V | TCJD337M006R0012E | Sphinx_V2:Capacitor_Tantalum_SMD__CP_EIA-7343-31_Kemet-D | no | Polymer tantalum; ESR12mOhm max; D case; positive stripe to core; local transient storage | 330uF +/-20%, 6.3V polymer tantalum, ESR12mOhm MAX at100kHz; D case; Tmax105C; Irms4.3/3.0/1.9A at45/85/105C; stripe=positive | https://datasheets.kyocera-avx.com/TCJ.pdf
C706 | 330u / 6.3V | TCJD337M006R0012E | Sphinx_V2:Capacitor_Tantalum_SMD__CP_EIA-7343-31_Kemet-D | no | Polymer tantalum; ESR12mOhm max; D case; positive stripe to core; local transient storage | 330uF +/-20%, 6.3V polymer tantalum, ESR12mOhm MAX at100kHz; D case; Tmax105C; Irms4.3/3.0/1.9A at45/85/105C; stripe=positive | https://datasheets.kyocera-avx.com/TCJ.pdf
C707 | 330u / 6.3V | TCJD337M006R0012E | Sphinx_V2:Capacitor_Tantalum_SMD__CP_EIA-7343-31_Kemet-D | no | Polymer tantalum; ESR12mOhm max; D case; positive stripe to core; local transient storage | 330uF +/-20%, 6.3V polymer tantalum, ESR12mOhm MAX at100kHz; D case; Tmax105C; Irms4.3/3.0/1.9A at45/85/105C; stripe=positive | https://datasheets.kyocera-avx.com/TCJ.pdf
C708 | 330u / 6.3V | TCJD337M006R0012E | Sphinx_V2:Capacitor_Tantalum_SMD__CP_EIA-7343-31_Kemet-D | yes | Polymer tantalum; ESR12mOhm max; D case; positive stripe to core; local transient storage | 330uF +/-20%, 6.3V polymer tantalum, ESR12mOhm MAX at100kHz; D case; Tmax105C; Irms4.3/3.0/1.9A at45/85/105C; stripe=positive | https://datasheets.kyocera-avx.com/TCJ.pdf
C711 | 100u / 6.3V | CL32A107MQVNNWE | Sphinx_V2:Capacitor_SMD__C_1210_3225Metric | no | Samsung 100uF X5R; simulate 25-120u per part; DC bias must be measured. | 100uF +/-20% 6.3V X5R 1210; max thickness2.8mm; bias/thermal effective capacitance needs qualification | https://product.samsungsem.com/mlcc/CL32A107MQVNNW.do
C712 | 100u / 6.3V | CL32A107MQVNNWE | Sphinx_V2:Capacitor_SMD__C_1210_3225Metric | no | Samsung 100uF X5R; simulate 25-120u per part; DC bias must be measured. | 100uF +/-20% 6.3V X5R 1210; max thickness2.8mm; bias/thermal effective capacitance needs qualification | https://product.samsungsem.com/mlcc/CL32A107MQVNNW.do
C713 | 100u / 6.3V | CL32A107MQVNNWE | Sphinx_V2:Capacitor_SMD__C_1210_3225Metric | no | Samsung 100uF X5R; simulate 25-120u per part; DC bias must be measured. | 100uF +/-20% 6.3V X5R 1210; max thickness2.8mm; bias/thermal effective capacitance needs qualification | https://product.samsungsem.com/mlcc/CL32A107MQVNNW.do
C714 | 100u / 6.3V | CL32A107MQVNNWE | Sphinx_V2:Capacitor_SMD__C_1210_3225Metric | yes | Samsung 100uF X5R; simulate 25-120u per part; DC bias must be measured. | 100uF +/-20% 6.3V X5R 1210; max thickness2.8mm; bias/thermal effective capacitance needs qualification | https://product.samsungsem.com/mlcc/CL32A107MQVNNW.do
C715 | 100u / 6.3V | CL32A107MQVNNWE | Sphinx_V2:Capacitor_SMD__C_1210_3225Metric | no | Samsung 100uF X5R; simulate 25-120u per part; DC bias must be measured. | 100uF +/-20% 6.3V X5R 1210; max thickness2.8mm; bias/thermal effective capacitance needs qualification | https://product.samsungsem.com/mlcc/CL32A107MQVNNW.do
C716 | 100u / 6.3V | CL32A107MQVNNWE | Sphinx_V2:Capacitor_SMD__C_1210_3225Metric | no | Samsung 100uF X5R; simulate 25-120u per part; DC bias must be measured. | 100uF +/-20% 6.3V X5R 1210; max thickness2.8mm; bias/thermal effective capacitance needs qualification | https://product.samsungsem.com/mlcc/CL32A107MQVNNW.do
C717 | 100u / 6.3V | CL32A107MQVNNWE | Sphinx_V2:Capacitor_SMD__C_1210_3225Metric | no | Samsung 100uF X5R; simulate 25-120u per part; DC bias must be measured. | 100uF +/-20% 6.3V X5R 1210; max thickness2.8mm; bias/thermal effective capacitance needs qualification | https://product.samsungsem.com/mlcc/CL32A107MQVNNW.do
C718 | 100u / 6.3V | CL32A107MQVNNWE | Sphinx_V2:Capacitor_SMD__C_1210_3225Metric | yes | Samsung 100uF X5R; simulate 25-120u per part; DC bias must be measured. | 100uF +/-20% 6.3V X5R 1210; max thickness2.8mm; bias/thermal effective capacitance needs qualification | https://product.samsungsem.com/mlcc/CL32A107MQVNNW.do
C721 | 1u / 10V | CL05A105KP5NNNC | Sphinx_V2:Capacitor_SMD__C_0402_1005Metric | no | 1uF +/-10% 10V X5R 0402 | https://product.samsungsem.com/mlcc/CL05A105KP5NNN.do
C722 | 1u / 10V | CL05A105KP5NNNC | Sphinx_V2:Capacitor_SMD__C_0402_1005Metric | no | 1uF +/-10% 10V X5R 0402 | https://product.samsungsem.com/mlcc/CL05A105KP5NNN.do
C723 | 1u / 10V | CL05A105KP5NNNC | Sphinx_V2:Capacitor_SMD__C_0402_1005Metric | no | 1uF +/-10% 10V X5R 0402 | https://product.samsungsem.com/mlcc/CL05A105KP5NNN.do
C724 | 1u / 10V | CL05A105KP5NNNC | Sphinx_V2:Capacitor_SMD__C_0402_1005Metric | no | 1uF +/-10% 10V X5R 0402 | https://product.samsungsem.com/mlcc/CL05A105KP5NNN.do
C725 | 1u / 10V | CL05A105KP5NNNC | Sphinx_V2:Capacitor_SMD__C_0402_1005Metric | no | 1uF +/-10% 10V X5R 0402 | https://product.samsungsem.com/mlcc/CL05A105KP5NNN.do
C726 | 1u / 10V | CL05A105KP5NNNC | Sphinx_V2:Capacitor_SMD__C_0402_1005Metric | no | 1uF +/-10% 10V X5R 0402 | https://product.samsungsem.com/mlcc/CL05A105KP5NNN.do
C727 | 1u / 10V | CL05A105KP5NNNC | Sphinx_V2:Capacitor_SMD__C_0402_1005Metric | no | 1uF +/-10% 10V X5R 0402 | https://product.samsungsem.com/mlcc/CL05A105KP5NNN.do
C728 | 1u / 10V | CL05A105KP5NNNC | Sphinx_V2:Capacitor_SMD__C_0402_1005Metric | no | 1uF +/-10% 10V X5R 0402 | https://product.samsungsem.com/mlcc/CL05A105KP5NNN.do
C729 | 1u / 10V | CL05A105KP5NNNC | Sphinx_V2:Capacitor_SMD__C_0402_1005Metric | no | 1uF +/-10% 10V X5R 0402 | https://product.samsungsem.com/mlcc/CL05A105KP5NNN.do
C730 | 1u / 10V | CL05A105KP5NNNC | Sphinx_V2:Capacitor_SMD__C_0402_1005Metric | no | 1uF +/-10% 10V X5R 0402 | https://product.samsungsem.com/mlcc/CL05A105KP5NNN.do
C731 | 1u / 10V | CL05A105KP5NNNC | Sphinx_V2:Capacitor_SMD__C_0402_1005Metric | no | 1uF +/-10% 10V X5R 0402 | https://product.samsungsem.com/mlcc/CL05A105KP5NNN.do
C732 | 1u / 10V | CL05A105KP5NNNC | Sphinx_V2:Capacitor_SMD__C_0402_1005Metric | no | 1uF +/-10% 10V X5R 0402 | https://product.samsungsem.com/mlcc/CL05A105KP5NNN.do
C733 | 1u / 10V | CL05A105KP5NNNC | Sphinx_V2:Capacitor_SMD__C_0402_1005Metric | no | 1uF +/-10% 10V X5R 0402 | https://product.samsungsem.com/mlcc/CL05A105KP5NNN.do
C734 | 1u / 10V | CL05A105KP5NNNC | Sphinx_V2:Capacitor_SMD__C_0402_1005Metric | no | 1uF +/-10% 10V X5R 0402 | https://product.samsungsem.com/mlcc/CL05A105KP5NNN.do
C735 | 1u / 10V | CL05A105KP5NNNC | Sphinx_V2:Capacitor_SMD__C_0402_1005Metric | no | 1uF +/-10% 10V X5R 0402 | https://product.samsungsem.com/mlcc/CL05A105KP5NNN.do
C736 | 1u / 10V | CL05A105KP5NNNC | Sphinx_V2:Capacitor_SMD__C_0402_1005Metric | no | 1uF +/-10% 10V X5R 0402 | https://product.samsungsem.com/mlcc/CL05A105KP5NNN.do
C741 | 100n / 16V | CL05B104KO5NNNC | Sphinx_V2:Capacitor_SMD__C_0402_1005Metric | no | 100nF +/-10% 16V X7R 0402 | https://product.samsungsem.com/mlcc/CL05B104KO5NNN.do
C742 | 100n / 16V | CL05B104KO5NNNC | Sphinx_V2:Capacitor_SMD__C_0402_1005Metric | no | 100nF +/-10% 16V X7R 0402 | https://product.samsungsem.com/mlcc/CL05B104KO5NNN.do
C743 | 100n / 16V | CL05B104KO5NNNC | Sphinx_V2:Capacitor_SMD__C_0402_1005Metric | no | 100nF +/-10% 16V X7R 0402 | https://product.samsungsem.com/mlcc/CL05B104KO5NNN.do
C744 | 100n / 16V | CL05B104KO5NNNC | Sphinx_V2:Capacitor_SMD__C_0402_1005Metric | no | 100nF +/-10% 16V X7R 0402 | https://product.samsungsem.com/mlcc/CL05B104KO5NNN.do
C745 | 100n / 16V | CL05B104KO5NNNC | Sphinx_V2:Capacitor_SMD__C_0402_1005Metric | no | 100nF +/-10% 16V X7R 0402 | https://product.samsungsem.com/mlcc/CL05B104KO5NNN.do
C746 | 100n / 16V | CL05B104KO5NNNC | Sphinx_V2:Capacitor_SMD__C_0402_1005Metric | no | 100nF +/-10% 16V X7R 0402 | https://product.samsungsem.com/mlcc/CL05B104KO5NNN.do
C747 | 100n / 16V | CL05B104KO5NNNC | Sphinx_V2:Capacitor_SMD__C_0402_1005Metric | no | 100nF +/-10% 16V X7R 0402 | https://product.samsungsem.com/mlcc/CL05B104KO5NNN.do
C748 | 100n / 16V | CL05B104KO5NNNC | Sphinx_V2:Capacitor_SMD__C_0402_1005Metric | no | 100nF +/-10% 16V X7R 0402 | https://product.samsungsem.com/mlcc/CL05B104KO5NNN.do
C749 | 100n / 16V | CL05B104KO5NNNC | Sphinx_V2:Capacitor_SMD__C_0402_1005Metric | no | 100nF +/-10% 16V X7R 0402 | https://product.samsungsem.com/mlcc/CL05B104KO5NNN.do
C750 | 100n / 16V | CL05B104KO5NNNC | Sphinx_V2:Capacitor_SMD__C_0402_1005Metric | no | 100nF +/-10% 16V X7R 0402 | https://product.samsungsem.com/mlcc/CL05B104KO5NNN.do
C751 | 100n / 16V | CL05B104KO5NNNC | Sphinx_V2:Capacitor_SMD__C_0402_1005Metric | no | 100nF +/-10% 16V X7R 0402 | https://product.samsungsem.com/mlcc/CL05B104KO5NNN.do
C752 | 100n / 16V | CL05B104KO5NNNC | Sphinx_V2:Capacitor_SMD__C_0402_1005Metric | no | 100nF +/-10% 16V X7R 0402 | https://product.samsungsem.com/mlcc/CL05B104KO5NNN.do
C753 | 100n / 16V | CL05B104KO5NNNC | Sphinx_V2:Capacitor_SMD__C_0402_1005Metric | no | 100nF +/-10% 16V X7R 0402 | https://product.samsungsem.com/mlcc/CL05B104KO5NNN.do
C754 | 100n / 16V | CL05B104KO5NNNC | Sphinx_V2:Capacitor_SMD__C_0402_1005Metric | no | 100nF +/-10% 16V X7R 0402 | https://product.samsungsem.com/mlcc/CL05B104KO5NNN.do
C755 | 100n / 16V | CL05B104KO5NNNC | Sphinx_V2:Capacitor_SMD__C_0402_1005Metric | no | 100nF +/-10% 16V X7R 0402 | https://product.samsungsem.com/mlcc/CL05B104KO5NNN.do
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

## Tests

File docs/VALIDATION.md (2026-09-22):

# Verification Plan and Evidence

## Schematic evidence

The [2026-09-22 final source review](FINAL_REVIEW_2026-09-22.md) records the completed independent recheck, including all component footprints and the companion controller tests.

The electrical source includes sheet 09 autonomous control and sheet 10 independent protection. The [ERC report](evidence/erc.json) records the KiCad version, configured checks, and violations for its recorded run. The [control connectivity review](evidence/hardware_review.json) records checked control, reset, and protection connections; the [documentation report](evidence/documentation_validation.json) records its own coverage. [PROVENANCE.json](../PROVENANCE.json) records design-file checksums and check scope. Match report versions/checksums to the current sources before relying on them. Use the regenerated [netlist](../schematic/exports/sphinx_power_v2.net.xml), [component list](../schematic/bom/component_list.csv), and evidence for actual sheet, part, and net counts after a change.

No V2 PCB measurements are included. This document does not declare new checks passed: consult each generated report for what was actually run. Electrical-rule checking establishes schematic consistency within the configured rules; it does not establish loop stability, transient pin voltages, thermal performance, power retention, or ASIC operating limits. The complete controller-independence acceptance matrix is in [AUTONOMOUS_POWER.md](AUTONOMOUS_POWER.md).

## Board measurements

| Area | Measurement |
|---|---|
| Assembly and startup | Inspect polarity, socket orientation, solder joints, default output inhibition, AUX, independent U901 3V3_CTRL, and USB/Pico supply separation with the ASIC absent. Verify a cold board defaults OFF, while Pico boot on an already active board does not change outputs. |
| ON/OFF and protective faults | Capture U903 P03 RUN_SET, RUN_LATCH, HW_FAULT_N, and rail enables. Exercise ON/OFF, STOP, control brownout, asserted eFuse fault, Core/I/O OVP, and temperature protection. A cleared run latch must never set again without explicit authorized startup; STOP cannot be overridden by a set pulse. Power commands and protective trips preserve U903 P02's reset request. |
| Pico independence | After a successful command, halt firmware, disconnect USB, reboot Pico, and remove only Pico power. With valid 12 V, verify retained rail/reset requests, unchanged regulator configuration, no bus clamp/back-power effect, and read-only reattachment. Perform tests with reset both released and asserted. |
| Input interruption | With USB both present and absent, measure VIN12, AUX5V, 3V3_CTRL, VIN12_VALID, eFuse FLT, RUN_LATCH, and output rails. Distinguish retained configuration, regulator-only POR, control brownout, and eFuse faults. Full input loss/discharge must default OFF on return. A retained latch alone does not prove retained PMBus configuration. |
| Hot startup | Heat U1001 before applying input. Across supply-ramp and temperature corners, measure detector readiness against the R1001-selected supervisor delay and verify no ON attempt enables the rails before hardware fault qualification. TMP302 §9 states functional readiness within 35 ms after VS reaches 1.4 V; test the complete circuit, including nonmonotonic ramps. Cooling cannot generate a start pulse. |
| Failed startup | Verify an unconfirmed commissioning profile, incomplete discharge, configuration mismatch, active protective fault, or failed latch readback leaves both supplies disabled. Confirm there is no automatic set-pulse retry and no inserted reset request. |
| Diagnostic warnings | Exercise PG loss, ordinary undervoltage/voltage deviation, PMBus warning status, USB inactivity, malformed commands, and telemetry read failures. Confirm observed warnings do not change power or reset requests. A lack of polling is not itself a fault and does not provide a complete event log. |
| Current and temperature policy | Confirm routine Core/I/O budgets and the 10 A target are warnings, not software shutdown thresholds. With Pico absent, verify the regulator's commissioned OC/OV/OT response, independent Core OVP, U1001 temperature trip/hysteresis, and U1002 I/O OVP threshold/latency. Record actual tolerances; do not claim a 14 A/100 ms hardware limiter or exact 2.025 V trip. Use a suitable load with the ASIC absent. |
| I/O enable | Measure EN relative to local VIN during cold start, rapid input loss, and command transitions. Include SS/TR and the intended temperature range. |
| Regulation | Use a local load to measure 0.30, 0.50, 0.75, 1.00, and 1.20 V at light load and increasing current, including the 10 A continuous design target. Record operating temperature and protection settings. |
| Range changes | Verify a scale-changing SET checks state, disables rail requests, confirms discharge/readback, and restores the prior requests only if the existing latch survives. There must be no RUN_SET pulse. STOP during programming must block restart even after release; recovery requires ON. SET while OFF must program/read back the target without enabling outputs. The explicit reset request remains unchanged. |
| Interrupted commands | Interrupt Pico execution at each ON/OFF/SET/RESET transaction boundary and drop USB before the final response. Do not report success or replay commands automatically; verify readback identifies the actual retained/intermediate state and leaves it unchanged until explicit recovery. |
| Loop stability | Measure gain and phase for each fitted capacitor population and feedback scale. Use ≥45° phase margin and ≥10 dB gain margin as engineering review criteria. |
| Load transients | Apply measured current steps at the socket with 100 ns and 1 µs edge settings and 10, 20, 50, and 100 µs pulse widths. Record actual edge rate, droop, overshoot, recovery, and repetition rate. |
| Explicit reset | Test local, remote, and U903-commanded reset; simultaneous requests; Pico absent/unprogrammed; disconnected remote cable; and remote-source power loss. With valid VIO and no request, confirm J1.54 is low. U903's last explicit request must persist through Pico power loss/reboot; each request independently asserts reset, and releasing one cannot override another. Keep the external clock running during intentional reset pulses. |
| Reset independence | With VIO held valid, vary CORE_PG, IO_VALID, VIN12_VALID, and RUN_LATCH and exercise ON/OFF/SET and warnings. Confirm none of these generates a reset request. Capture actual J1.54 during supply ramps as well; distinguish analog behavior during invalid VIO from deliberate logic-controlled reset. |
| Telemetry | Calibrate voltage, shunt readings, zero-current offset, and U904 AIN0/AIN1 ratiometric temperature readings, including ADC loading of the 100 kΩ NTC network. Verify addresses 0x10/0x20/0x40/0x41/0x48 and read-only attachment. Record instrument settings and temperature. |
| Control bus | Establish board-side capacitance ≤80 pF and measure SDA/SCL low levels, rise times, noise and ground offset at every receiver. Verify U903 junction temperature remains ≤100°C throughout the qualified load/airflow envelope; its SDA current allowance above 100°C is incompatible with the present 2.2 kΩ pullups. The remote U1001 temperature alone does not establish this limit. |
| Functionality | Establish power and clock, explicitly reset the DUT, load and execute one kernel, and compare its output. Capture supply behavior at kernel start and completion. Include nominal operation and selected low-voltage and boost points. |
| Steady power | Run the kernel in a large back-to-back loop, allow electrical and thermal readings to settle, and collect averaged Core/I/O voltage, current, and power. Record warning status and airflow; distinguish board/socket supply power from die power and account for downstream board loads. |
| Sustained operation | Run selected operating points for eight hours, logging resets, errors, supply extrema, current, temperature, and airflow. |

Choose pulsed-load amplitude and duty cycle within the configured input, current, and thermal limits. The 10 A continuous target is not an instantaneous current clamp or a required load at every voltage. Numerical droop acceptance limits are not assigned; use the measurements to assess board delivery and the observed ASIC operating region.

Measure rising and falling load edges. Trigger actual ASIC captures on the single functionality kernel's start and completion and on transitions into or out of the power loop. Supplemental qualification can vary idle intervals. Probe socket power and ground locally and document bandwidth and probe loading. INA226 telemetry is intended for steady averaged power; it does not establish the minimum transient voltage or capture every pin event.

## Test record

Each record should identify the board and DUT, hardware revision, fitted capacitor population, controller revision, register readback, clock settings, input wiring, load waveform, probe locations, instrument configuration, and temperature. Attach the waveforms supporting supply extrema and reset events. Keep board-side observations separate from inferred die behavior.

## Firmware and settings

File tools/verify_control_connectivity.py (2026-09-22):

#!/usr/bin/env python3
"""Check the current V2 control electrical contract and procurement records.

Run from any directory with Python 3; no third-party packages, Git history, or
network are required. The exported netlist, catalog, purchase list, and existing
ERC report are inputs. This does not regenerate exports or test a physical board.
"""

import argparse
import csv
import hashlib
import json
import sys
import xml.etree.ElementTree as ET
from datetime import datetime, timezone
from pathlib import Path

NETLIST_PATH = "schematic/exports/sphinx_power_v2.net.xml"
# Reviewed physical connections, including complete fault and enable interfaces.
# Update this contract only after reviewing an intentional electrical change.
CONTROL_PIN_CONTRACT = {'C1001': {'1': '3V3_CTRL', '2': 'GND'},
 'C1002': {'1': '3V3_CTRL', '2': 'GND'},
 'C306': {'1': 'VIN12', '2': 'IO_EN_INHIBIT'},
 'C307': {'1': 'IO_EN', '2': 'GND'},
 'C506': {'1': '3V3_CTRL', '2': 'GND'},
 'C901': {'1': 'AUX5V', '2': 'GND'},
 'C902': {'1': '3V3_CTRL', '2': 'GND'},
 'C903': {'1': '3V3_CTRL', '2': 'GND'},
 'C904': {'1': 'PICO_3V3', '2': 'GND'},
 'C905': {'1': '3V3_CTRL', '2': 'GND'},
 'C906': {'1': '3V3_CTRL', '2': 'GND'},
 'C907': {'1': 'BOARD_NTC', '2': 'GND'},
 'J1': {'54': 'reset'},
 'J602': {'1': 'ZED_3V3', '2': 'ZED_RESET_OD'},
 'Q301': {'1': 'IO_EN_CTRL', '2': 'GND', '3': 'IO_EN_PULLDOWN'},
 'Q302': {'1': 'IO_EN_INHIBIT', '2': 'GND', '3': 'IO_EN'},
 'Q601': {'1': 'RESET_BASE', '2': 'GND', '3': 'reset'},
 'Q602': {'1': 'RESET_ASSERT', '2': 'GND', '3': 'RESET_BASE'},
 'Q901': {'1': 'CLEAR_REQUEST', '2': 'GND', '3': 'HW_FAULT_N'},
 'R1001': {'1': '3V3_CTRL', '2': 'SUPERVISOR_CT'},
 'R1002': {'1': '1V8', '2': 'IO_OV_SENSE'},
 'R1003': {'1': 'IO_OV_SENSE', '2': 'GND'},
 'R1004': {'1': 'UNUSED_P12', '2': 'GND'},
 'R1005': {'1': 'UNUSED_P13', '2': 'GND'},
 'R1006': {'1': 'UNUSED_P14', '2': 'GND'},
 'R1007': {'1': 'UNUSED_P15', '2': 'GND'},
 'R1008': {'1': 'UNUSED_P16', '2': 'GND'},
 'R1009': {'1': 'UNUSED_P17', '2': 'GND'},
 'R210': {'1': 'CORE_EN', '2': 'GND'},
 'R211': {'1': '3V3_CTRL', '2': 'CORE_PG'},
 'R303': {'1': 'IO_EN', '2': 'GND'},
 'R305': {'1': 'VIN12', '2': 'IO_EN'},
 'R306': {'1': 'VIN12', '2': 'IO_EN_INHIBIT'},
 'R307': {'1': 'IO_EN_CTRL', '2': 'GND'},
 'R308': {'1': 'IO_EN_INHIBIT', '2': 'IO_EN_PULLDOWN'},
 'R408': {'1': '3V3_CTRL', '2': 'BOARD_NTC'},
 'R409': {'1': 'BOARD_NTC', '2': 'GND'},
 'R411': {'1': 'RESET_ASSERT', '2': 'GND'},
 'R503': {'1': '0V75', '2': 'CORE_OV_SENSE'},
 'R504': {'1': 'CORE_OV_SENSE', '2': 'GND'},
 'R506': {'1': '3V3_CTRL', '2': 'HW_FAULT_N'},
 'R507': {'1': 'RUN_SET', '2': 'GND'},
 'R509': {'1': 'CORE_REQ', '2': 'GND'},
 'R510': {'1': 'IO_REQ', '2': 'GND'},
 'R511': {'1': '1V8', '2': 'IO_UV_SENSE'},
 'R512': {'1': 'IO_UV_SENSE', '2': 'GND'},
 'R513': {'1': '3V3_CTRL', '2': 'IO_VALID'},
 'R514': {'1': 'VIN12', '2': 'VIN12_UV_SENSE'},
 'R515': {'1': 'VIN12_UV_SENSE', '2': 'GND'},
 'R516': {'1': '3V3_CTRL', '2': 'VIN12_VALID'},
 'R602': {'1': '1V8', '2': 'reset'},
 'R603': {'1': '1V8', '2': 'RESET_BASE'},
 'R604': {'1': 'RESET_BASE', '2': 'GND'},
 'R605': {'1': 'ZED_3V3', '2': 'ZED_OPTO_A'},
 'R901': {'1': 'PICO_3V3', '2': 'PICO_SDA'},
 'R902': {'1': 'PICO_3V3', '2': 'PICO_SCL'},
 'R903': {'1': 'CLEAR_REQUEST', '2': 'GND'},
 'SW502': {'1': 'HW_FAULT_N', '2': 'GND'},
 'SW601': {'1': 'RESET_BASE', '2': 'GND'},
 'U1001': {'1': '3V3_CTRL', '2': 'GND', '3': 'HW_FAULT_N', '4': 'GND', '5': '3V3_CTRL', '6': 'GND'},
 'U1002': {'1': 'HW_FAULT_N',
           '2': 'GND',
           '3': 'IO_OV_REF',
           '4': 'IO_OV_SENSE',
           '5': 'IO_OV_REF',
           '6': '3V3_CTRL'},
 'U101': {'1': 'INPUT_UVLO',
          '10': 'unconnected-(U101-ITIMER-Pad10)',
          '2': 'INPUT_OVLO',
          '3': 'unconnected-(U101-AUXOFF-Pad3)',
          '4': 'HW_FAULT_N',
          '5': 'VIN_FUSED',
          '6': 'VIN12',
          '7': 'INPUT_DVDT',
          '8': 'GND',
          '9': 'INPUT_ILM'},
 'U201': {'1': 'CORE_PG', '27': 'CORE_EN', '33': 'CORE_SENSE_P', '34': 'CORE_SENSE_N'},
 'U301': {'13': 'IO_EN', '14': '1V8'},
 'U401': {'1': 'PICO_SDA',
          '10': 'unconnected-(U401-GPIO7-Pad10)',
          '11': 'unconnected-(U401-GPIO8-Pad11)',
          '12': 'unconnected-(U401-GPIO9-Pad12)',
          '14': 'unconnected-(U401-GPIO10-Pad14)',
          '15': 'unconnected-(U401-GPIO11-Pad15)',
          '16': 'unconnected-(U401-GPIO12-Pad16)',
          '2': 'PICO_SCL',
          '20': 'unconnected-(U401-GPIO15-Pad20)',
          '32': 'unconnected-(U401-GPIO27_ADC1-Pad32)',
          '36': 'PICO_3V3',
          '39': 'PICO_VSYS',
          '4': 'unconnected-(U401-GPIO2-Pad4)',
          '5': 'unconnected-(U401-GPIO3-Pad5)',
          '6': 'unconnected-(U401-GPIO4-Pad6)',
          '7': 'unconnected-(U401-GPIO5-Pad7)',
          '9': 'unconnected-(U401-GPIO6-Pad9)'},
 'U501': {'1': 'HW_FAULT_N',
          '2': 'GND',
          '3': 'REF1V242',
          '4': 'CORE_OV_SENSE',
          '5': 'REF1V242',
          '6': '3V3_CTRL'},
 'U502': {'1': 'HW_FAULT_N',
          '2': 'GND',
          '3': '3V3_CTRL',
          '4': 'SUPERVISOR_CT',
          '5': '3V3_CTRL',
          '6': '3V3_CTRL'},
 'U503': {'1': 'RUN_SET_CLEAN',
          '2': '3V3_CTRL',
          '3': 'unconnected-(U503-Q_N-Pad3)',
          '4': 'GND',
          '5': 'RUN_LATCH',
          '6': 'HW_CLEAR_N',
          '7': '3V3_CTRL',
          '8': '3V3_CTRL'},
 'U504': {'1': 'RUN_LATCH',
          '10': 'GND',
          '11': 'unconnected-(U504-4Y-Pad11)',
          '12': 'GND',
          '13': 'GND',
          '14': '3V3_CTRL',
          '2': 'CORE_REQ',
          '3': 'CORE_EN',
          '4': 'RUN_LATCH',
          '5': 'IO_REQ',
          '6': 'IO_EN_CTRL',
          '7': 'GND',
          '8': 'unconnected-(U504-3Y-Pad8)',
          '9': 'GND'},
 'U507': {'1': 'RUN_SET',
          '2': 'GND',
          '3': 'HW_FAULT_N',
          '4': 'HW_CLEAR_N',
          '5': '3V3_CTRL',
          '6': 'RUN_SET_CLEAN'},
 'U508': {'1': 'IO_VALID',
          '2': 'GND',
          '3': 'IO_UV_SENSE',
          '4': 'IO_UV_REF',
          '5': 'IO_UV_REF',
          '6': '3V3_CTRL'},
 'U509': {'1': 'VIN12_VALID',
          '2': 'GND',
          '3': 'VIN12_UV_SENSE',
          '4': 'VIN12_UV_REF',
          '5': 'VIN12_UV_REF',
          '6': '3V3_CTRL'},
 'U601': {'1': 'ZED_OPTO_A', '2': 'ZED_RESET_OD', '3': 'GND', '4': 'RESET_BASE'},
 'U901': {'1': 'AUX5V', '2': 'GND', '3': 'AUX5V', '4': 'unconnected-(U901-NC-Pad4)', '5': '3V3_CTRL'},
 'U902': {'1': '3V3_CTRL',
          '2': 'PMBUS_SDA',
          '3': 'PMBUS_SCL',
          '4': 'GND',
          '5': 'GND',
          '6': 'PICO_SCL',
          '7': 'PICO_SDA',
          '8': 'PICO_3V3'},
 'U903': {'1': 'unconnected-(U903-INT_N-Pad1)',
          '10': 'HW_FAULT_N',
          '11': 'CORE_PG',
          '12': 'GND',
          '13': 'IO_VALID',
          '14': 'VIN12_VALID',
          '15': 'UNUSED_P12',
          '16': 'UNUSED_P13',
          '17': 'UNUSED_P14',
          '18': 'UNUSED_P15',
          '19': 'UNUSED_P16',
          '2': 'GND',
          '20': 'UNUSED_P17',
          '21': 'GND',
          '22': 'PMBUS_SCL',
          '23': 'PMBUS_SDA',
          '24': '3V3_CTRL',
          '3': 'GND',
          '4': 'CORE_REQ',
          '5': 'IO_REQ',
          '6': 'RESET_ASSERT',
          '7': 'RUN_SET',
          '8': 'CLEAR_REQUEST',
          '9': 'RUN_LATCH'},
 'U904': {'1': 'GND',
          '10': 'PMBUS_SCL',
          '2': 'unconnected-(U904-ALERT_RDY_N-Pad2)',
          '3': 'GND',
          '4': 'BOARD_NTC',
          '5': '3V3_CTRL',
          '6': 'GND',
          '7': 'GND',
          '8': '3V3_CTRL',
          '9': 'PMBUS_SDA'}}

U504_PINMAP = {
    "1": ("1A", "RUN_LATCH", "input"),
    "2": ("1B", "CORE_REQ", "input"),
    "3": ("1Y", "CORE_EN", "output"),
    "4": ("2A", "RUN_LATCH", "input"),
    "5": ("2B", "IO_REQ", "input"),
    "6": ("2Y", "IO_EN_CTRL", "output"),
    "7": ("GND", "GND", "power_in"),
    "8": ("3Y", "unconnected-(U504-3Y-Pad8)", "output+no_connect"),
    "9": ("3A", "GND", "input"),
    "10": ("3B", "GND", "input"),
    "11": ("4Y", "unconnected-(U504-4Y-Pad11)", "output+no_connect"),
    "12": ("4A", "GND", "input"),
    "13": ("4B", "GND", "input"),
    "14": ("VCC", "3V3_CTRL", "power_in"),
}
NONPURCHASE_REFS = {
    "NT601", "NT602", "TP4", "TP607", "TP7", "TP801",
    "TP802", "TP803", "TP804", "TP805", "TP806",
}


def sha256(data):
    return hashlib.sha256(data).hexdigest()


def parse_netlist(data):
    root = ET.fromstring(data)
    components = {item.get("ref"): item for item in root.find("components")}
    pins, nodes, nets = {}, {}, {}
    for net in root.find("nets"):
        name = net.get("name")
        if name in nets:
            raise ValueError(f"Duplicate net name: {name}")
        nets[name] = net
        for node in net:
            key = (node.get("ref"), node.get("pin"))
            if key in pins:
                raise ValueError(f"Pin appears on multiple nets: {key}")
            pins[key], nodes[key] = name, node
    return root, components, pins, nodes, nets


def mpn(component):
    prop = component.find("property[@name='MPN']")
    return prop.get("value") if prop is not None else None


def main():
    parser = argparse.ArgumentParser(description=__doc__)
    parser.add_argument("--output", type=Path, help="Optional evidence JSON path")
    args = parser.parse_args()
    project = Path(__file__).resolve().parents[1]
    output = args.output or project / "docs/evidence/hardware_review.json"
    current = (project / NETLIST_PATH).read_bytes()
    new_root, new_comps, new_pins, new_nodes, new_nets = parse_netlist(current)
    errors = []
    expected = {(ref, pin): net for ref, pins in CONTROL_PIN_CONTRACT.items()
                for pin, net in pins.items()}
    pin_differences = [
        {"reference": ref, "pin": pin, "expected": net,
         "actual": new_pins.get((ref, pin))}
        for (ref, pin), net in expected.items()
        if new_pins.get((ref, pin)) != net
    ]
    exact_nets = (
        "RUN_SET", "RUN_SET_CLEAN", "RUN_LATCH", "HW_FAULT_N", "HW_CLEAR_N",
        "CORE_EN", "CORE_REQ", "IO_REQ", "IO_EN_CTRL", "IO_EN", "IO_EN_PULLDOWN",
        "IO_EN_INHIBIT", "RESET_ASSERT", "VIN12_VALID",
        "RESET_BASE", "ZED_OPTO_A", "ZED_3V3", "ZED_RESET_OD", "reset",
        "CORE_PG", "IO_VALID", "CORE_OV_SENSE", "VIN12_UV_SENSE", "IO_UV_SENSE",
        "PICO_3V3", "PICO_SDA", "PICO_SCL", "CLEAR_REQUEST", "SUPERVISOR_CT",
        "BOARD_NTC", "IO_OV_REF", "IO_OV_SENSE",
        "UNUSED_P12", "UNUSED_P13", "UNUSED_P14", "UNUSED_P15", "UNUSED_P16", "UNUSED_P17",
    )
    net_member_differences = []
    for net in exact_nets:
        wanted = {key for key, value in expected.items() if value == net}
        actual = {key for key, value in new_pins.items() if value == net}
        # Reset also has dedicated probe access, specified separately below.
        if net == "reset":
            wanted.add(("TP7", "1"))
        if wanted != actual:
            net_member_differences.append({"net": net, "missing": sorted(wanted-actual),
                                           "unexpected": sorted(actual-wanted)})
    if pin_differences or net_member_differences:
        errors.append("The current netlist differs from the reviewed control electrical contract.")
    obsolete_nets = {"RESET_PERMIT", "RESET_RELEASE", "RESET_RELEASE_OK"} & set(new_nets)
    obsolete_parts = {"U506", "C507"} & set(new_comps)
    if obsolete_nets or obsolete_parts:
        errors.append("Obsolete power-qualified reset gates or nets are still present.")
    reset_parts = {
        "Q601": "MMBT3904-7-F", "Q602": "DMN62D2UQ-7",
        "R411": "RC0603FR-07100KL", "R602": "RC0603FR-0710KL",
        "R603": "RC0603FR-0721K5L", "R604": "RC0603FR-07100KL",
        "R516": "RC0603FR-0710KL",
        "C901": "CL21B475KOFNNNE", "C902": "CL21B475KOFNNNE",
        "U901": "TLV75533PDBVR", "U902": "ISO1640BDR", "U903": "TCA9535PWR",
        "U904": "ADS1115IDGSR", "U1001": "TMP302BDRLR", "U1002": "TLV3011AIDBVR",
        "Q901": "DMN62D2UQ-7", "R1001": "RC0603FR-07100KL",
        "R1002": "RT0603BRD0712K6L", "R1003": "RT0603BRD0720KL",
    }
    for ref, expected_mpn in reset_parts.items():
        if ref not in new_comps or mpn(new_comps[ref]) != expected_mpn:
            errors.append(f"Reset/monitor bias part mismatch: {ref} must be {expected_mpn}.")
    for pin, function in (("1", "G"), ("2", "S"), ("3", "D")):
        node = new_nodes.get(("Q602", pin))
        if node is None or node.get("pinfunction") != f"{function}_{pin}":
            errors.append(f"Q602 physical pin {pin} must be {function}.")
    if len(new_comps) != 247 or len(new_nets) != 146:
        errors.append("Current V2 component/net counts differ from 247/146.")
    # Every Pico signal except isolated I2C must be NC. Supply and ground are
    # the only other allowed connections; a stray direct diagnostic wire fails.
    pico_allowed = {"GND", "PICO_VSYS", "PICO_3V3", "PICO_SDA", "PICO_SCL"}
    for (ref, pin), net in new_pins.items():
        if ref == "U401" and net not in pico_allowed and not net.startswith("unconnected-"):
            errors.append(f"Pico physical pin {pin} directly touches board state: {net}")
        if ref == "U401" and net.startswith("unconnected-") and "no_connect" not in new_nodes[(ref, pin)].get("pintype", ""):
            errors.append(f"Pico unused pin {pin} lacks a deliberate NC marker")
    for pin, function in (("1", "G"), ("2", "S"), ("3", "D")):
        if new_nodes[("Q901", pin)].get("pinfunction") != f"{function}_{pin}":
            errors.append(f"Q901 physical pin {pin} must be {function}")
    physical_pin_differences = []
    for pin, (function, net, pin_type) in U504_PINMAP.items():
        node = new_nodes.get(("U504", pin))
        if node is None or (
            new_pins[("U504", pin)] != net
            or node.get("pinfunction") != f"{function}_{pin}"
            or node.get("pintype") != pin_type
        ):
            physical_pin_differences.append(pin)
    u504 = new_comps.get("U504")
    if u504 is None or (
        mpn(u504) != "74LVC08AT14-13"
        or u504.findtext("value") != "74LVC08AT14-13"
        or u504.findtext("footprint") != "Sphinx_V2:Package_SO__TSSOP-14_4.4x5mm_P0.65mm"
        or physical_pin_differences
    ):
        errors.append("U504 part, package, physical pin function, or pin type mismatch.")
    if new_nodes.get(("U503", "3")) is None or new_nodes[("U503", "3")].get("pintype") != "output+no_connect":
        errors.append("U503 Q-bar must be explicitly unconnected.")
    catalog_path = project / "schematic/bom/parts_catalog.json"
    buy_path = project / "schematic/bom/BUY_LIST.csv"
    catalog_bytes, buy_bytes = catalog_path.read_bytes(), buy_path.read_bytes()
    catalog = json.loads(catalog_bytes)
    parts = catalog["parts"]
    catalog_refs, bom_differences = {}, []
    for part in parts:
        refs, dnp = part["references"], part["dnp_references"]
        if len(refs) != part["quantity_per_board"] or len(refs) - len(dnp) != part["fitted_per_board"]:
            bom_differences.append([part["mpn"], "catalog reference/fitted count mismatch"])
        for ref in refs:
            if ref in catalog_refs:
                bom_differences.append([ref, "duplicate catalog reference"])
            catalog_refs[ref] = part["mpn"]
            if ref not in new_comps or mpn(new_comps[ref]) != part["mpn"]:
                bom_differences.append([ref, part["mpn"], mpn(new_comps[ref]) if ref in new_comps else None])
    nonpurchase = set(new_comps) - set(catalog_refs)
    if nonpurchase != NONPURCHASE_REFS:
        bom_differences.append(["nonpurchase reference set", sorted(nonpurchase)])
    with buy_path.open(encoding="utf-8-sig", newline="") as handle:
        rows = list(csv.DictReader(handle))
    if len(rows) != len(parts):
        bom_differences.append(["CSV and catalog row count mismatch"])
    for part, row in zip(parts, rows):
        for field in row:
            expected_value = part.get(field)
            if isinstance(expected_value, list):
                expected_value = " ".join(expected_value)
            else:
                expected_value = "" if expected_value is None else str(expected_value)
            if row[field] != expected_value:
                bom_differences.append([part["mpn"], field, expected_value, row[field]])
    if bom_differences:
        errors.append("BOM/netlist/CSV mismatch.")
    erc_path = project / "docs/evidence/erc.json"
    erc_bytes = erc_path.read_bytes()
    erc = json.loads(erc_bytes)
    violations = [violation for sheet in erc.get("sheets", [])
                  for violation in sheet.get("violations", [])]
    if not erc.get("sheets") or violations:
        errors.append("The existing ERC report is missing sheets or reports violations.")
    report = {
        "review": "Current V2 autonomous power electrical contract and BOM audit",
        "generated_at_utc": datetime.now(timezone.utc).isoformat(),
        "result": "PASS" if not errors else "FAIL",
        "reproduce": "python3 tools/verify_control_connectivity.py",
        "current": {"path": NETLIST_PATH, "sha256": sha256(current),
                    "components": len(new_comps), "nets": len(new_nets)},
        "connectivity": {
            "netlist_pins": len(new_pins), "contract_pins_checked": len(expected),
            "full_control_pin_contract": CONTROL_PIN_CONTRACT,
            "exact_net_membership_checked": list(exact_nets),
            "pin_differences": pin_differences,
            "net_member_differences": net_member_differences,
            "scope": "Independent control supply, isolated Pico interface, retained expander requests, board ADC, standalone thermal and IO overvoltage shutdown, STOP, run latch, all enable/reset gates and local/remote reset.",
        },
        "U504": {
            "manufacturer": "Diodes Incorporated", "mpn": "74LVC08AT14-13",
            "package": "TSSOP-14; 4.4 x 5 mm body; 0.65 mm pitch",
            "datasheet": "https://www.diodes.com/datasheet/download/74LVC08A.pdf",
            "datasheet_revision": "DS35261 Rev. 4-2, September 2023",
            "source_checked_on": "2026-09-19",
            "datasheet_pages": {"pinmap": 2, "drive_and_Ioff": 4, "ordering": 7, "package": 8},
            "physical_pinmap": {pin: {"function": f, "net": n, "type": t}
                                for pin, (f, n, t) in U504_PINMAP.items()},
            "physical_pin_differences": physical_pin_differences,
            "drive_assessment": "R307 load <=3.6/(270*0.99)=13.47 mA. At VCC=3 V, the conservative 24 mA drive row specifies VOH >=2.2 V through 85 C and >=2.0 V through 125 C, above Q301's 1.8 V gate-drive test point. This does not establish full-temperature MOSFET or transient performance.",
            "power_off_assessment": "At VCC=0 and VI/VO=0..3.6 V, Ioff <=10 uA through 85 C and <=20 uA through 125 C. Existing output pull-downs remain. This is not a brownout or board-transient guarantee.",
        },
        "fault_behavior": {
            "assessment": "STOP and hardware-fault detectors clear U503 asynchronously through U507. Fault recovery creates no RUN_SET rising edge and therefore does not set the latch by itself.",
            "firmware_condition": "No automatic RUN_SET pulses after a fault, boot or reconnect; a fresh ON request is required. A faulty controller can issue another pulse, so the circuit is not an independent prohibition of all controller-initiated restarts.",
            "reset_policy": "With valid VIO, reset is asserted only by SW601, U601, or Q602. R603 biases Q601 on from VIO by default. PG, VIN12_VALID, and RUN_LATCH do not qualify reset release.",
            "input_loss_limit": "Retention requires continuously valid board input. Complete board-power loss defaults OFF. Partial input brownout can reset regulator and control domains differently; it requires physical characterization. U509 remains diagnostic only.",
        },
        "bom": {
            "catalog_path": "schematic/bom/parts_catalog.json", "catalog_sha256": sha256(catalog_bytes),
            "buy_list_path": "schematic/bom/BUY_LIST.csv", "buy_list_sha256": sha256(buy_bytes),
            "catalog_order_lines": len(parts), "csv_order_lines": len(rows),
            "purchased_component_references": len(catalog_refs),
            "nonpurchase_references": sorted(nonpurchase),
            "mpn_references_checked": len(catalog_refs),
            "alignment_differences": bom_differences,
        },
        "erc": {"path": "docs/evidence/erc.json", "sha256": sha256(erc_bytes),
                "reported_violations": len(violations), "reported_date": erc.get("date"),
                "ignored_checks": erc.get("ignored_checks", []),
                "regenerated_by_this_script": False},
        "physical_tests_performed": False,
        "firmware_tests_performed_by_this_script": False,
        "limitations": [
            "No board measurements, analog simulation, thermal qualification, or real-device firmware execution.",
            "The script checks exported XML and existing ERC evidence; regenerate both after schematic edits. Firmware tests and visual review are separate checks.",
            "Datasheet drive and power-off review is recorded here; no network or stock check is performed by this script.",
        ],
        "errors": errors,
    }
    output.parent.mkdir(parents=True, exist_ok=True)
    output.write_text(json.dumps(report, indent=2, ensure_ascii=False) + "\n")
    print(f"{report['result']}: {len(expected)} contract pins, {len(catalog_refs)} procurement MPNs, {len(rows)} order lines, {len(violations)} ERC violations")
    print(f"Evidence: {output}")
    for error in errors:
        print(error, file=sys.stderr)
    return 1 if errors else 0


if __name__ == "__main__":
    raise SystemExit(main())

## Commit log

2026-09-19 Sphinx V2
    [01_input_aux.kicad_sch, 02_core_regulator.kicad_sch, 03_io_and_telemetry.kicad_sch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]
2026-09-21 Decouple DUT reset and input diagnostics from power interlocks
    Use explicit manual, ZedBoard, and Pico reset requests. Route input-voltage validity to telemetry while retaining protective power interlocks. Synchronize requirements, schematic exports, BOM, and verification evidence.
    [01_input_aux.kicad_sch, 03_io_and_telemetry.kicad_sch, 04_usb_control.kicad_sch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]
2026-09-22 Make V2 power state independent of Pico
    Add an independently powered retained control domain, isolated I2C, hardware temperature and I/O overvoltage protection, and correct the socket keepout. Align operating requirements, BOM, schematic exports, and validation evidence.
    Complete the final source review: zero ERC violations, 247 footprint/BOM matches, 80 ASIC pin checks, and 51 companion host tests including 122 interrupted-write cases. Record physical qualification limits and external companion firmware hashes.
    [02_core_regulator.kicad_sch, 03_io_and_telemetry.kicad_sch, 04_usb_control.kicad_sch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]
